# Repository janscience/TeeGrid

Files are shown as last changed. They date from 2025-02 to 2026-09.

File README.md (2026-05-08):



# TeeGrid

Record electric fish with electrode arrays based on
[Teensy](https://www.pjrc.com/teensy/) microcontrollers.

Based on the [TeeRec](https://github.com/janscience/TeeRec) library,
inspired by Stefan Mucha's
[EOD-Logger](https://github.com/muchaste/EOD-Logger), the
[MicroConfig](https://github.com/janscience/MicroConfig) library, the
[ESensors](https://github.com/janscience/ESensors) library, and the
[Teensy_Amp](https://github.com/janscience/Teensy_Amp) amplifiers.

teensyamp

## R4 logger with sensors

Logger for 2 to 16 channels based on
[Teensy_Amp R4.1](https://github.com/janscience/Teensy_Amp/tree/main/R4.1) or
[Teensy_Amp R4.2](https://github.com/janscience/Teensy_Amp/tree/main/R4.2) with additional environmental sensors. [Read more](examples/R4-sensors-logger/).

submerged logger

## R4 logger

Logger for 2 to 16 channels based on
[Teensy_Amp R4.1](https://github.com/janscience/Teensy_Amp/tree/main/R4.1) or
[Teensy_Amp R4.2](https://github.com/janscience/Teensy_Amp/tree/main/R4.2). [Read
more](examples/R4-logger/).

## R40 logger

Logger for 2 to 8 channels based on [Teensy_Amp
  R4.0](https://github.com/janscience/Teensy_Amp/tree/main/R4.0). [Read
  more](examples/R40-logger/).

## 8-channel logger

Logger for 8 channels based on [Teensy_Amp
  R1.0](https://github.com/muchaste/Teensy_Amp/tree/main/R1.0).  [Read
  more](examples/8channel-logger/).

8channel

## 8-channel logger with sensors

A variant of the [8-channel logger](8channel-logger/) that
supports a variety of environmental sensors. [Read
more](examples/8channel-sensors-logger/).

## Configuration and testing GUI

The [`loggerconf`](utils/loggerconf.py) GUI allows you to configure
the loggers, set the real-time clock, and provides many diagnostic features.

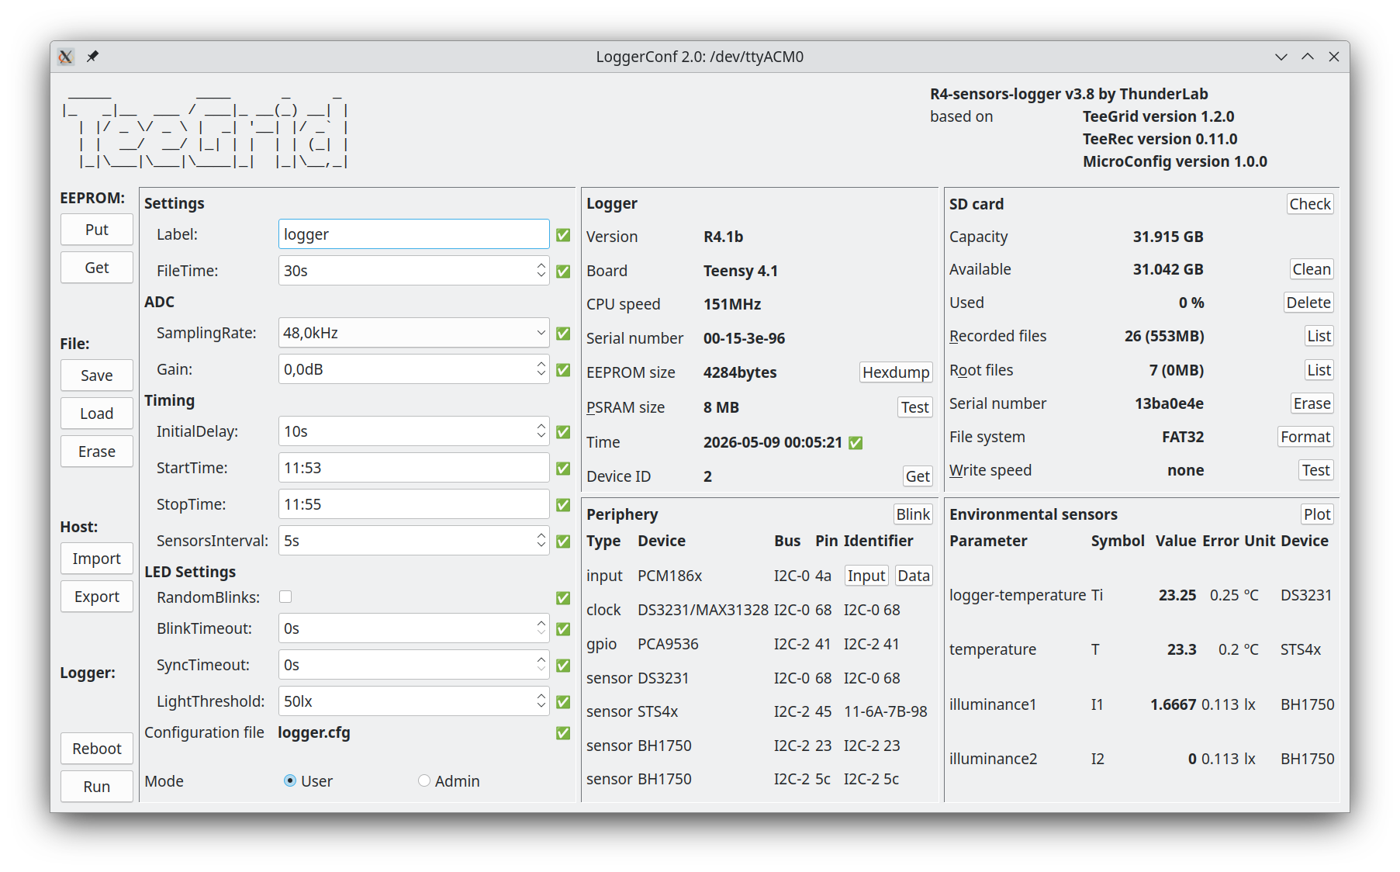
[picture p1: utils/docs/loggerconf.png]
loggerconf


You need to install `pymicroconfig` first, as described
[here](https://github.com/janscience/MicroConfig/tree/main/pymicroconfig).

And you need to install [`pyqtgraph`](https://www.pyqtgraph.org/):
```
pip install pyqtgraph
```

Then navigate to `Arduion/libraries/TeeGrid/utils` and run
```
python loggerconf.py
```

## Housings

- [PVC-tube housings](doc/pvc-tube-housing)

housing

## Electrodes

- [Stainless-steel electrodes](doc/steel-electrodes)

electrodes

## Installation

- [Installation instructions](doc/installation) for the TeeGrid
  library and sketches.

## Resources

Ideas to solve the syncrhonization problem of multiple loggers:

- [Low-cost synchronization of high-speed audio and video recordings
  in bio-acoustic experiments](https://doi.org/10.1242/jeb.173724)
- [Bio-acoustic tracking and localization using heterogeneous,
  scalable microphone
  arrays](https://doi.org/10.1038/s42003-021-02746-2)

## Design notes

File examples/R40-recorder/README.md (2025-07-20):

# R4.0 recorder

Recorder for 2, 4, 6, or 8 channels based on [TeensyAmp
  R4.0](https://github.com/janscience/Teensy_Amp/tree/main/R4.0)
  connected to a [Teensy 4.1](https://www.pjrc.com/store/teensy41.html).

Designed by Jan Benda in July 2025.

## Dependencies

The [`R40-recorder.ino`](R40-recorder.ino) sketch is based on the
[TeeRec](https://github.com/janscience/TeeRec) library.

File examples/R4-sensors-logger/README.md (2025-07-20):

# R4.x sensors logger

Logger for 2 to 16 channels based on

- [Teensy_Amp R4.1](https://github.com/janscience/Teensy_Amp/tree/main/R4.1) and/or
- [R4.2](https://github.com/janscience/Teensy_Amp/tree/main/R4.2)
  connected to a
- [Teensy 4.1](https://www.pjrc.com/store/teensy41.html)

with additional sensors (see [Sensors-V1](../../doc/sensors/sensors-v1)).

Software based on the

- [TeeRec](https://github.com/janscience/TeeRec) and the
- [ESensors](https://github.com/janscience/ESensors) libraries.

Designed by Jan Benda and Patrick Weygoldt in September 2023.

submerged logger

## Assembly

Connect the wires from the [electrodes](../../doc/steel-electrodes) to the screw terminals of the amplifier...

channels

... using this [color code](https://github.com/janscience/TeeGrid/tree/main/doc/steel-electrodes#international-color-code)

Connect the coin battery and the temperature sensor:

periphery

connections

- Status LED: plug onto the two pins on the
  [R4.1](https://github.com/janscience/Teensy_Amp/tree/main/R4.1) PCB
  top left corner. When running the
  [`R4-sensors-logger.ino`](R4-sensors-logger.ino) sketch, and this
  LED does not light up, then unplug, turn by 180 degrees, and plug in
  again.

- Coin battery: make sure the +3.3V (hopefully red) is on the side,
  and ground (hopefully black) is in the center of the Teensy. Better
  is to check the polarity of the coin battery using a multimeter.

- Temperature sensor: the data wire goes on third pin (counted from
  the SD card end of the Teensy, pin 35). Power is the red cable,
  ground is the red cable with the black line on the outside.

## Installation

See the [installation instructions](../../doc/install.md) for the
TeeGrid library.

## Software setup

The behavior of the logger sketch can be modfied in various
ways. Either by editing some variables directly in the sketch, as
described here, or by a configuration file provided on the SD card, as
described in the next section.

*WARNING* the settings of the config file overwrite the settings made
 in the sketch!

For editing the sketch, open the
[`R4-sensors-logger.ino`](R4-sensors-logger.ino) sketch in the Arduino
IDE (`File` - `Open`, `Ctrl-O`, or `File` - `Examples` - `TeeGrid` -
`R4-senosrs-logger`) and edit it appropriately.  In the top section
marked as `Default settings` you may adapt some settings according to
your needs as described in the next sections.

Once you modified the sketch to your needs, compile and upload it to
the Teensy (`Ctrl-U`). Open the serial monitor (`Ctrl-Shift-M`) and
check the output of the sketch.

### Data acquisition

The first section is about the data acquisition:

- `NCHANNELS`: the number of channels you want to record. If you use a
  single [Teensy_Amp R4.1](https://github.com/janscience/Teensy_Amp/tree/main/R4.1)
  or [R4.2](https://github.com/janscience/Teensy_Amp/tree/main/R4.2) then set this to 8.
  If you use [both of them stacked
  together](https://github.com/janscience/Teensy_Amp/tree/main/R4.1-R4.2),
  then set it to 16.
- `SAMPLING_RATE`: the sampling rate you want to use (48000 or 96000 Hertz).
- `PREGAIN`: the gain of the preamplifier, either 10 (default) or 1
  (for recording electric eels). *Make sure this is is set to the right number!*
- `GAIN`: additional gain of the ADC in dB. 0: x1, 20: x10, 40: x100.

For wavefish use an amplifier with a pregain of 10 and set the gain
to 20dB. For electric eels, use an amplifier with a pregain of 1 and
set the gain to 0dB.

### File naming and size

The second section is about the files that store the data on the SD
card.

- `PATH`: name of the directory, in which the files are stored.
- `FILENAME`: name of the files that store the recorded data. See
  below for special strings to insert data and time.
- `FILE_SAVE_TIME`: each file will store that many seconds of the
  continuous recording.
- `INITIAL_DELAY`: after startup, wait for the specified time in
  seconds before writing data to files.

#### Special strings for the file name

The following special strings in the file name are replaced by
the current date, time, or a number:

- `DATE`: the current date as ISO string (YYYY-MM-DD)
- `SDATE`: "short date" - the current date as YYYYMMDD
- `TIME`: the current time as ISO string but with dashes instead of colons (HH-MM-SS)
- `STIME`: "short time" - the current time as HHMMSS
- `DATETIME`: the current date and time as YYYY-MM-DDTHH-MM-SS
- `SDATETIME`: "short data and time" - the current date and time as YYYYMMDDTHHMMSS
- `ANUM`: a two character string numbering the files: 'aa', 'ab', 'ac', ..., 'ba', 'bb', ...
- `NUM`: a two character string numbering the files: '01', '02', '03', ..., '10', '11', ...
- `NUM3`: a three character string numbering the files: '001', '002', '003', ..., '010', '011', ..., '100', '101', ...
- `NUM4`: a four character string numbering the files: '0001', '0002', '0003', ..., '0010', '0011', ..., '0100', '0101', ..., '1000', '1001', ...

### Pins and Sensors

- `LED_PIN`: the [Teensy pin](https://github.com/janscience/Teensy_Amp/blob/main/R4.1/images/teensy41-R41-pinout.png) to which the LED on the amplifier is connected to.
- `TEMP_PIN`: the [Teensy pin](https://github.com/janscience/Teensy_Amp/blob/main/R4.1/images/teensy41-R41-pinout.png) to which the DATA wire of the [Dallas
  DS18x20](https://github.com/janscience/ESensors/blob/main/docs/chips/ds18x20.md)
  temperature sensor is connected to.
- `SENSORS_INTERVAL`: interval between sensor readings in seconds

## Configuration file

Most of the settings described above can be configured via a
configuration file. Simply place a configuration file named
[`logger.cfg`](logger.cfg) into the root folder of the SD card. If
present, this file is read once on startup. The configuration file
will overwrite the settings made in the
[`R4-sensors-logger.ino`](R4-sensors-logger.ino) sketch.

The content of the configuration file should look like this:

```txt
Settings:
  Path:            recordings
  FileName:        logger1-SDATETIME.wav
  FileTime:        5min
  InitialDelay:    10s
  SensorsInterval: 10.0s
ADC:
  SamplingRate: 48.0kHz
  NChannels:    16
  Gain:         20.0dB
``` 

Everything behind '#' is a comment. All lines without a colon are
ignored.  Unknown keys are ignored but reported. Times and frequencies
understand various units (s, min, h, kHz, MHz). Check the serial
monitor of the Arduino IDE (`Ctrl+Shif+M`) to confirm the settings.

## Real-time clock

For proper naming of files, the real-time clock needs to be set to the
right time. The easiest way to achieve this, is to compile and upload
the [`R4-sensors-logger.ino`](R4-sensors-logger.ino) sketch from the
Arduino IDE. The upload also sets the on-bard real-time clock to the
time of the computer. Use the serial monitor to check the output of
the sketch. At the beginning it reports the time. Disconnect the
Teensy from the USB and simply reconnect it. If it then reports on the
serial monitor the right time, the real time clock is properly set and
is properly powered by the coin battery.

Alternatively, you may copy a file named `settime.cfg` into the root
folder of the SD card. This file contains a single line with a date
and a time in the following format:
``` txt
YYYY-MM-DDTHH:MM:SS
```

In a shell you might generate this file via
```sh
date +%FT%T > settime.cfg
```
and then edit this file to some time in the near future.

Insert the SD card into the Teensy. Start the Teensy exactly at the
time that is written into the `settime.cfg` file by connecting it to
power. On start up the
[`R4-sensors-logger.ino`](R4-sensors-logger.ino) sketch reads in the
`settime.cfg` file, sets the real-time clock to this time, and then
deletes the file from the SD card to avoid resetting the time at the
next start up.

## Check logger function

Run the logger from the Arduino IDE and check the output on the serial
monitor (`Ctrl+Shif+M`). You should then see something like the
following. The comments after `#` have been inserted afterwards to
explain what is important:

```txt
=======================================================================

RTC (on-board) current time: 2024-08-12T10:43:13      # this should be the current time and not 2019-01-01T00:00:00

Configuration file "logger.cfg" not found or empty.   # if you use a configuration file, it should be reported here

Settings:                                             # check whether these configuration settings are right
  Path:            recordings
  FileName:        logger1-SDATETIME.wav
  FileTime:        300s
  PulseFreq:       0Hz
  InitialDelay:    10s
  SensorsInterval: 10.0s
ADC:
  SamplingRate: 48.0kHz
  NChannels:    16
  Gain:         0.0dB

1 of 1 environmental sensor available, read every 10s:  # check whether all sensors are detected
  water-temperature T_water (ºC):	 on DS18B20 device (ID: 28 43 AA 67 B2 23 06 10) at a resolution of 0.06ºC.

Setup PCM186x 0 on TDM 0: configured for 4 channels  # make sure all 4 chips are detected and configured for 4 channels
Setup PCM186x 1 on TDM 0: configured for 4 channels
Setup PCM186x 2 on TDM 1: configured for 4 channels
Setup PCM186x 3 on TDM 1: configured for 4 channels

TDM settings:                                        # check sampling rate and channels
  rate:       48.0kHz
  resolution: 32bits
  channels:   16
  swap l/r:   1
  buffer:     2.73s (2097152 samples)
  DMA time:   1.3ms

Save recorded data in folder "recordings".

logger1-20240812T104327.wav                         # this is the first file in which recorded data are stored
2024-08-12T10:43:27: T_water = 27.12ºC              # this is the measured temperature
2024-08-12T10:43:35: T_water = 27.12ºC
2024-08-12T10:43:45: T_water = 27.12ºC
...
```

## Logging

1. *Format the SD card.* (see section below)
2. Optional: Copy your logger.cfg file onto the SD card.
3. Insert the SD card into the Teensy.
4. Connect the Teensy to a battery/power bank.
5. Close the housing.
6. Place the logger whereever you want to record electric fishes.
7. Let the logger record the data.
8. Check the status LED whether it blinks every 5 secods. If it is not
   blinking, then something is wrong.
9. After many hours (or days, depending on the capacity of your powerbanks),
   collect the logger.
10. Open it, and disconnect the Teensy from the powerbank.
11. Optionally repeat 4. - 10. with a freshly charged powerbank
    until the SD card is full.
12. Take out the SD card and store the data on a harddrive.
    Don't forget to backup the data.

### Formatting the SD card

The SD card needs to be reformatted once in a while. The logger runs
until the battery is drained and therefore cannot properly close the
last files. This leaves the file system in a corrupted state, which
apparently results in very long delays when writing to the SD card
again.

You may use the sketch provided by the SdFat library for formatting
the SD card directly on a Teensy: In the Arduino IDE menu select
`File` - `Examples`, browse to the last section ("Examples from custom
libraries"), select `SdFat` and then `SdFormatter`. Upload the script
on Teensy and open the serial monitor. Follow the instructions on the
serial monitor.

Or use the `SdFormatter` script provided in TeeGrid. This is the same
script as the one described above, but without user interaction. When
running it will erase and format the SD card inserted into the Teensy.
You find this script under `File` - `Examples` - `TeeGrid` -
`SdFormatter`.

Formatting from a computer also helps, but this omits the erasing
part.

### Status LED

The on-board LED of the Teensy and the LED of the [Teensy_Amp
R4.1](https://github.com/janscience/Teensy_Amp/tree/main/R4.1) or
[R4.2](https://github.com/janscience/Teensy_Amp/tree/main/R4.2)
indicate the following events:

- On startup the LED is switched on during the initialization of the
  data acqusition and SD card. This can last for up to 2 seconds
  (timeout for establishing a serial connection with a computer).

- For the time of the initial delay (nothing is recorded to SD card)
  a double-blink every 2s is emitted.

- Normal operation, i.e. data acquisition is running and data are
  written to SD card: the LED briefly flashes every 5 seconds (file
  time larger than 30s) or every 2 seconds (file time smaller than
  30s).

- Whenever a file is closed and the next one opened, the LED lights for
  1 second. Then it continues with flashes every 5 seconds.

- The LED is switched off if no data can be written on the SD card (no
  SD card present or SD card full) or data acquisition is not working.
  In this case, connect the Teensy to a computer and open the serial
  monitor of the Arduino IDE (`Ctrl+Shif+M`). On startup the settings
  for the data acquisition are reported and in case of problems an
  error message is displayed.

## Files

Analog input data are stored on the SD card as wave files in the
directory specified by `PATH` with names `FILENAME`. The metadata
in these files indicate the time when the file was created and the
overall gain of the hardware.

You may use the Python
[audioio](https://github.com/janscience/audioio) package to read the
recorded channels and the metadata. Or use the
[DataLoader](https://github.com/bendalab/thunderlab/blob/main/src/thunderlab/dataloader.py)
from the [thunderlab](https://github.com/bendalab/thunderlab)
package. The latter applies the gain setings directly to the data.

For viewing the data, you may use any audio tool. Or check out
[audian](https://github.com/bendalab/audian).

The sensor data are stored as a csv file with the very same name as
the first data file, but with `-sensors.csv` added to it.

## Improvements

- Add sensor for illumination and water conductivity. Make a PCB for this!

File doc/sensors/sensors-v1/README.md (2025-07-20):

# Sensors V1

Temperature and illumination sensors and status LEDs for
[R4-sensors-logger](../../../examples/R4-sensors-logger).

## Sensors

### Rohm BH1750 ambient light sensor

- [data sheet](https://github.com/janscience/ESensors/blob/main/docs/chips/datasheets/bh1750.pdf)
- [ESensors library](https://github.com/janscience/ESensors/blob/main/docs/chips/bh1750.md)

### TI TMP119 temperature sensor

- [data sheet](https://github.com/janscience/ESensors/blob/main/docs/chips/datasheets/tmp119.pdf)

## Circuit

- [EAGLE schematics file](Sensors-V1.sch)
- [EAGLE circuit board](Sensors-V1.brd)

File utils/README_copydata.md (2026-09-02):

# `copydata.py`

Copies logger SD cards onto the field drive: compress, sort, verify. An
alternative to `copydata.sh` for card sets big enough that you want the copy to
prove itself. Standard library only — no `pip install` on a field laptop. Needs
`wavpack`/`wvunpack`; `zstd` as fallback, `--codec none` needs nothing.

New to it: start with the [tutorial](TUTORIAL_copydata.md).

## Use

```
python3 utils/copydata.py list                                    # what is on the cards
python3 utils/copydata.py copy /media/me/HDD/iriri26
python3 utils/copydata.py verify /media/me/HDD/iriri26 --only-unverified --jobs 4
python3 utils/copydata.py restore DEST ./unpacked                 # back to plain .wav
```

`copy` is resumable: re-running skips every file the manifest records as fully
written, so an interruption costs you only the file it died on.

## Verification

Every file is sha256'd while it streams off the card. That hash is free — it is
the same read — and it goes into `copy_manifest.jsonl` on the drive. Reading
files *back* is what costs time:

| `--verify` | reads back | 4 x 500 GB |
|---|---|---|
| `sample` (default) | 5% of each deployment, every sidecar | ~6.3 h |
| `full` | everything | ~12 h |
| `none` | nothing | ~6 h |

`sample` does not give up proof, it defers it. `verify` checks the drive against
the stored hashes and does not need the cards, so run it once they are out of
the reader — but before reformatting anything.

`--sample-percent P` (default 5) is a share and not a count because folders
differ by three orders of magnitude: a 20 min test is 4 files, a 3 day recording
at 5 min per file is ~864. At the default that 3 day folder gets 44 probes, one
per ~1.7 h of recording.

## Codec

`wavpack -f` is the default. Measured on three flona2025 WAVs (16 ch, 48 kHz,
16-bit, 461 MB) spanning a busy night grid, a grid with 8 dead channels, and a
quiet line recording:

| codec | saved | compress MB/s/core | decompress |
|---|---|---|---|
| `zstd -3` | 84.7 % | ~258 | ~700 |
| `gzip -6` | 86.6 % | ~27 | ~660 |
| **`wavpack -f`** | **88.6 %** | **~93** | ~88 |
| `wavpack -h -x4` | 89.2 % | ~3.5 | ~90 |
| `xz -6` | 91.5 % | ~0.9 | ~143 |

`gzip` is beaten on both axes. These are not general-purpose bytes — the
recordings use only 3-11 of their 16 bits, so per-channel prediction plus Rice
coding fits them better than an LZ matcher. `wavpack -f` also beats wavpack's
own default level here. FLAC is not an option at all: the format caps at 8
channels. `xz` is the smallest but runs at ~1 MB/s/core, slower than the cards
themselves — use it at the lab (`restore`, then `copy --codec xz`).

In the field the cards are the bottleneck, so the compression is free.

## What ends up on the drive

Sessions are named `<site>-<grid>-<dev>-<timestamp>` and are filed to match:

```
DEST/
├── copy_manifest.jsonl        # per file: source, sha256, codec, WAV metadata
├── copy_logs/
├── site01/grid01/site01-grid01-dev01-20260826T175746/
│   ├── site01-grid01-dev01-20260826T175746.wv
│   └── site01-grid01-dev01-20260826T175746-sensors.csv   # sidecars stay plain
├── site02/grid01/site02-grid01-dev01-20260827T090000__mac1b9999/   # only on a real collision
└── logger24A-20260826T1757/   # name does not parse: left at the top level
```

A folder whose name does not match the convention is left at the top level
rather than filed under a guessed site, so old and new cards can be copied in
one run. `--flat` turns the nesting off.

The manifest is part of the archive. Without it you have files but no proof they
match the cards, and `verify` and `restore` have nothing to check against.

## Worth knowing

* **Never writes to a card, never deletes anything.** Ejecting and reformatting
  stay manual, on purpose.
* **Copied files are read-only (`0444`).** Files only, not directories, so
  resume and `verify` still work. `--no-protect` disables it. Does nothing on
  exFAT/NTFS — the summary says so rather than pretending.
* **The custom `LIST`/`INFO` chunk survives.** `wvunpack` reconstructs a
  byte-identical `.wav`, `DTIM` included. It can also be read without decoding:
  wavpack keeps the original RIFF header in the first 8 KB of the `.wv`.
* **0-byte WAVs are skipped** (`--keep-empty` to copy them). A scan of 23,699
  flona2025 WAVs found 61, always the last file of a deployment.
* **`verify --jobs N`** checks N files at a time (default `min(4, cores)`) and
  writes each outcome back, so a file that fails loses any earlier "verified"
  claim.
* **`--codec-threads`** defaults to `cores / cards`, which keeps each card
  streaming sequentially — the right pattern for SD cards and a spinning drive.

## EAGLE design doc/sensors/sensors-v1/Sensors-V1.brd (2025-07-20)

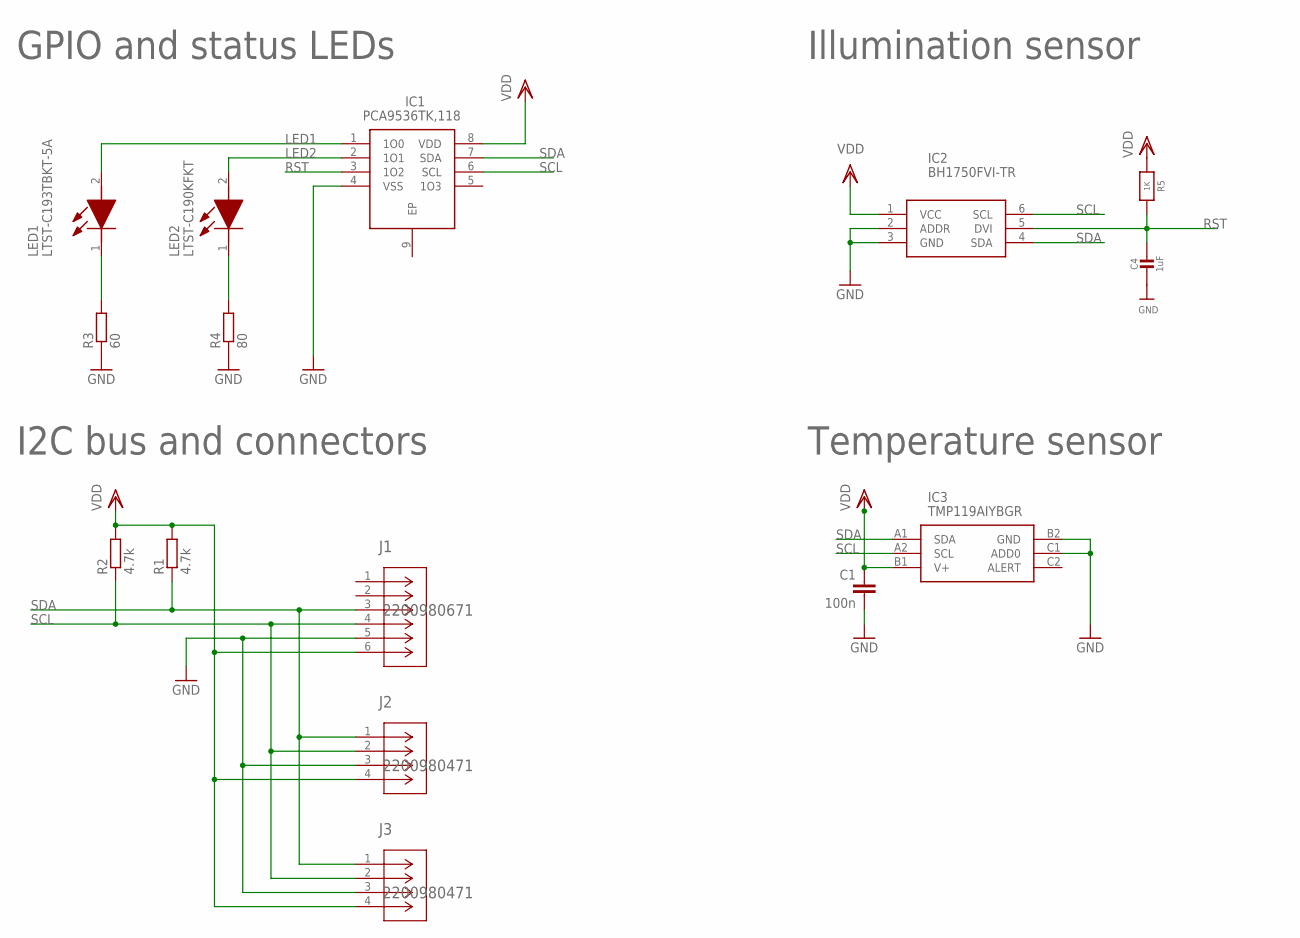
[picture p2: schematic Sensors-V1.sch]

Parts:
C1: 100n; C0603
C4: 1uF; 0603-NO
IC1: PCA9536TK,118; SON50P300X300X100-9N
IC2: BH1750FVI-TR; WSOF6
IC3: TMP119AIYBGR; BGA6C40P2X3_95X149X52
J1: 2200980671; CONN_2200980000-SD_06_MOL
J2, J3: 2200980471; CONN_2200980000-SD_04_MOL
LED1: LTST-C193TBKT-5A; LEDC1608X45N
LED2: LTST-C190KFKT; LEDC1607X80N
R1, R2: 4.7k; R0603
R3: 60; R0603
R4: 80; R0603
R5: 1K; 0603-NO

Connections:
GND: C1.2, C4.2, IC1.4 (VSS), IC2.2 (ADDR), IC2.3 (GND), IC3.B2 (GND), IC3.C1 (ADD0), J1.5, J2.3, J3.3, R3.1, R4.1
LED1: IC1.1 (1O0), LED1.2 (A)
LED2: IC1.2 (1O1), LED2.2 (A)
unnamed: LED1.1 (K), R3.2
unnamed: LED2.1 (K), R4.2
RST: C4.1, IC1.3 (1O2), IC2.5 (DVI), R5.2
SCL: IC1.6 (SCL), IC2.6 (SCL), IC3.A2 (SCL), J1.4, J2.2, J3.2, R2.1
SDA: IC1.7 (SDA), IC2.4 (SDA), IC3.A1 (SDA), J1.3, J2.1, J3.1, R1.1
VDD: C1.1, IC1.8 (VDD), IC2.1 (VCC), IC3.B1 (V+), J1.6, J2.4, J3.4, R1.2, R2.2, R5.1

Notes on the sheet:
Temperature sensor
Illumination sensor
GPIO and status LEDs
I2C bus and connectors

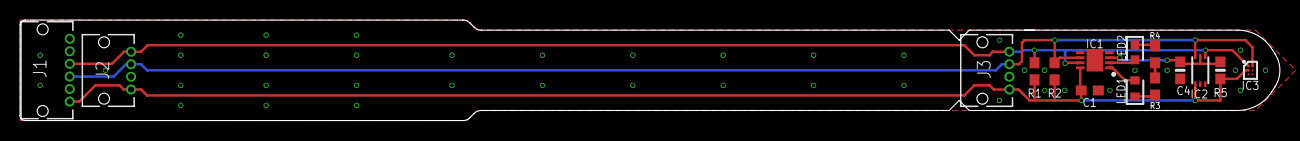
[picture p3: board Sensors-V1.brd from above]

Board: 2 copper layers, 125.4 x 10.0 mm, 15 parts (0 on the bottom side), 9 nets.

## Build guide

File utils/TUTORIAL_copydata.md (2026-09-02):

# Getting a stack of SD cards onto the field drive

Walkthrough of `copydata.py`. Reference material — codec table, archive layout,
all options — is in [`README_copydata.md`](README_copydata.md).

Three things in one pass: **copy** each card into its own deployment folder
filed by site and grid, **shrink** every WAV to about an eighth without losing a
sample, and **check** the copy so you can reformat the card without crossing
your fingers.

Plug in the cards and the destination drive. Nothing else to prepare — the tool
finds the cards itself and never writes to one. You need `python3` and
`wavpack`; if something is missing it says so.

## 1. Look

```
python3 utils/copydata.py list
```

Reads the WAV headers, shows what it found and where each thing would go.
Writes nothing. Worth doing once to spot a card that did not mount, or a logger
that recorded far less than expected.

## 2. Copy

```
python3 utils/copydata.py copy /media/you/FIELD_HDD/iriri26
```

Prints a plan, asks once, then works. Cards are read in parallel, one file at a
time each.

```
  TOTAL: 7 files, 23.4 MB
  skipping 1 empty (0-byte) wav(s) -- the file the logger had open
  codec: wavpack -f
  verify: spot check 5 of 7 files (71.4%)
  estimated on destination: ~3.0 MB  (free: 28.8 GB)
```

Then walk away. Expect roughly card speed; compression is not the bottleneck.

## 3. Read the last lines

```
copied   : 7 files, 23.4 MB read -> 3.0 MB written
ratio    : 0.126 (87.4% saved)

Spot check passed: 5 of 7 files were read back and re-hashed.
Every file's source hash is in the manifest, so any of them can still be
proven -- but the rest are NOT yet confirmed on the destination.
```

Read that literally, both ways. For the checked files the drive holds exactly
what the card held. The rest are written and hashed, but not yet read back —
that is step 4.

If you see `FAILED (n)`: **do not reformat the cards.** Run the same command
again; finished files are skipped and only the broken ones retried.

## 4. Prove the rest

The spot check is sized to catch a card or drive going bad — 5% of each
deployment, evenly spread. It is not proof of every file. That is one more
command:

```
python3 utils/copydata.py verify /media/you/FIELD_HDD/iriri26 \
    --only-unverified --jobs 4
```

It reads the destination, not the cards, so **unplug them first** and run it
over supper. Expect roughly half the time the copy took. You want
`bad: 0   missing: 0`. Anything else and the cards are still the only good copy.

## 5. Only now, reformat

Ejecting and reformatting are left to you. The tool never deletes anything.

## Getting `.wav` files back

```
python3 utils/copydata.py restore DEST ./unpacked --only site01/grid01
```

`--only` matters: one deployment is ~270 GB unpacked. Each restored file is
checked against its stored checksum on the way out.

Often you do not need this. `wvunpack` seeks, so a reader can pull a window
straight out of a `.wv`: a 10 s window costs 0.19 s whether it starts at 0 s or
4 min in, and a full 300 s file decodes in 5.9 s (~50x realtime).

```
wvunpack -q -y --skip=00:02:00 --until=+00:00:10 -o - FILE.wv
```

Note the header of a *partial* decode is synthetic and carries no `LIST`/`INFO`
metadata. That metadata is not lost — wavpack keeps the original RIFF header in
the first 8 KB of the `.wv`, and `copy_manifest.jsonl` has the same fields
already parsed.

## The commands

| | |
|---|---|
| `list` | what is on the cards, where it would go |
| `copy DEST` | copy, compress, spot-check |
| `verify DEST` | prove the drive against the manifest, cards not needed |
| `restore DEST OUT` | back to plain `.wav` |

## Worth knowing

* The drive is filed by site and grid: `DEST/site01/grid01/<session>/`.
* Copied files are read-only. Resume and `verify` still work; `--no-protect`
  turns it off.
* Re-running `copy` is safe and resumes.
* In a hurry: `--verify none` skips the spot check, `--verify full` reads
  everything back and roughly doubles the run.

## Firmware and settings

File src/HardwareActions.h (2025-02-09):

/*
  HardwareActions - Actions for diagnosing external hardware.
  Created by Jan Benda, January 5th, 2025.
*/

#ifndef HardwareActions_h
#define HardwareActions_h


#include <Action.h>
#include <Menu.h>
#include <ESensors.h>


class ESensorsAction : public Action {

 public:

  /* Initialize and add to default menu. */
  ESensorsAction(const char *name, ESensors &sensors);

  /* Initialize and add to configuration menu. */
  ESensorsAction(Menu &menu, const char *name, ESensors &sensors);

protected:

  ESensors &Sensors;
};


class ESensorSensorsAction : public ESensorsAction {

 public:

  using ESensorsAction::ESensorsAction;

  /* Print infos about available environmental sensors. */
  virtual void execute(Stream &stream=Serial, unsigned long timeout=0,
		       bool echo=true, bool detailed=false);
};


class ESensorDevicesAction : public ESensorsAction {

 public:

  using ESensorsAction::ESensorsAction;

  /* Print infos about available environmental sensor devices. */
  virtual void execute(Stream &stream=Serial, unsigned long timeout=0,
		       bool echo=true, bool detailed=false);
};


class ESensorRequestAction : public ESensorsAction {

 public:

  using ESensorsAction::ESensorsAction;

  /* Request sensor values. */
  virtual void execute(Stream &stream=Serial, unsigned long timeout=0,
		       bool echo=true, bool detailed=false);
};


class ESensorValuesAction : public ESensorsAction {

 public:

  using ESensorsAction::ESensorsAction;

  /* Print sensor values. If detailed, just get previously requested values.
     Otherwise request and read them. */
  virtual void execute(Stream &stream=Serial, unsigned long timeout=0,
		       bool echo=true, bool detailed=false);
};


#endif

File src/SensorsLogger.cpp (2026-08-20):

#include <PowerSave.h>
#include <LoggerSettings.h>
#include <SensorsLogger.h>


SensorsLogger::SensorsLogger(Input &aiinput,
			     ESensors &sensors,
			     SDCard &sdcard,
			     RTClock &rtclock,
			     Blink &blink) :
  Logger(aiinput, sdcard, rtclock, blink),
  Sensors(sensors),
  NLightSensors(0),
  IlluminationThreshold(0.0) {
}


SensorsLogger::SensorsLogger(Input &aiinput,
			     ESensors &sensors,
			     SDCard &sdcard,
			     RTClock &rtclock,
			     Blink &blink,
			     Blink &errorblink,
			     Blink &syncblink) :
  Logger(aiinput, sdcard, rtclock, blink, errorblink, syncblink),
  Sensors(sensors),
  NLightSensors(0),
  IlluminationThreshold(0.0) {
}


void SensorsLogger::setupSensors() {
  Sensors.setPrintTime(ESensors::NO_TIME);
  Sensors.start();
  for (uint8_t k=0; k<Sensors.sensors(); k++) {
    if (Sensors[k].available() && (strcmp(Sensors[k].unit(), "lx") == 0) &&
	(NLightSensors < MaxLight))
      LightSensors[NLightSensors++] = &Sensors[k];
  }
}


void SensorsLogger::checkVoltage(float minvoltage) {
  ESensor *vbat = Sensors.sensor("battery-voltage");
  if (vbat != 0 && minvoltage > 0.0) {
    float volt = vbat->read();
    if (volt < minvoltage) {
      stop();
      StatusLED.switchOff();
      ErrorLED.switchOff();
      SyncLED.switchOff();
      Serial.printf("HALT --- battery voltage %.2fV lower than %.2fV!\n",
		    volt, minvoltage);
      Serial.println();
      Serial.println();
      Serial.flush();
      shutdown_teensy();
    }
  }
}


void SensorsLogger::startSensors(float interval,
				 float lightthreshold) {
  IlluminationThreshold = lightthreshold;
  Sensors.setInterval(interval);
  Sensors.setPrintTime(ESensors::ISO_TIME);
  Sensors.reportDevices();
  Sensors.report();
  Sensors.start();
  Sensors.read();
  Sensors.start();
  Sensors.read();
}


void SensorsLogger::start(float filetime) {
  Logger::start(filetime);
  openSensorsFile();
}


void SensorsLogger::start(float filetime, Config &config) {
  Logger::start(filetime, config);
  openSensorsFile();
}


void SensorsLogger::start(float filetime, Config &config,
			  Menu &amplifier) {
  Logger::start(filetime, config, amplifier);
  openSensorsFile();
}


void SensorsLogger::openSensorsFile() {
  String sname = File.name();
  sname.replace(".wav", "-sensors");
  Sensors.openCSV(*Disk, sname.c_str());
  Serial.print("Write sensor data to ");
  Serial.println(sname);
}


bool SensorsLogger::storeSensors() {
  if (Sensors.update(StatusLED.isOn() || SyncLED.isOn())) {
    if (Sensors.pendingCSV())
      Sensors.writeCSV();
    Sensors.print(true, true);
    // strongest illumination:
    if (NLightSensors > 0) {
      float illumination = 0.0;
      for (size_t k=0; k<NLightSensors; k++) {
	if (LightSensors[k]->value() > illumination)
	  illumination = LightSensors[k]->value();
      }
      if (illumination < IlluminationThreshold) {
	StatusLED.disablePins();
	SyncLED.disablePins();
      }
      else {
	StatusLED.enablePins();
	SyncLED.enablePins();
      }
    }
    return true;
  }
  return false;
}


void SensorsLogger::closeSensorsFile() {
  Sensors.closeCSV();
}


bool SensorsLogger::update(float stopvoltage) {
  Logger::update(stopvoltage);
  return storeSensors();
}


void SensorsLogger::synchronize(float stopvoltage) {
  checkVoltage(stopvoltage);
}


void SensorsLogger::stop() {
  closeSensorsFile();
  Logger::stop();
}

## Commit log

2024-10-24 fixed PulseFreq and possible sampling rates
    [LoggerFileStorage.cpp, R4-logger.ino, R4-sensors-logger.ino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]
2024-11-24 [loggerconf] added device to logger info
2024-11-26 [loggerconf] added list root file button
2024-11-28 [loggerconf] switch into detailed mode
2024-11-29 [loggerconf] switch off echoing input
2024-11-30 [loggerconf] try to reboot already connected Teensy
    [LoggerFileStorage.cpp, R4-logger.ino]
2024-12-02 [LoggerFileStorage] set current CPU speed to WaveHeader
2024-12-04 [loggerconf] transmit detcts wrong value and still returns to main menu
    [R4-logger.ino]
2024-12-07 [loggerconf] added SD card formatting buttons
2024-12-13 [loggerconf] added run button
2024-12-14 [loggerconf] fixed mising unit bug
    [R4-logger.ino]
2024-12-14 [loggerconf] removed some prints
2024-12-16 [loggerconf] delete button next to used
2025-01-04 [SensorsLoggerFileStorage] support sensors
2025-01-05 [HardwareActions] report sensor infos
2025-01-05 [loggerconf] added sensors info
2025-01-06 [loggerconf] added input devices
2025-01-10 [R4-logger] added input devices to menu
2025-01-10 [R4-logger] added rtclock devices to diagnostics
2025-01-10 [loggerconf] update for sensor devices
2025-01-11 [HardwareActions] sensor readings
2025-01-11 [HardwareActions] fixed sensor readings
    [R4-sensors-logger.ino, SensorsLogger.cpp]
2025-01-11 [HardwareActions] sensor request
2025-01-11 [HardwareActions] read or get sensor
2025-01-11 [loggerconf] display sensor values
2025-01-13 [loggerconf] adapted SensorsInfo to removed colon
2025-01-18 [loggerconf] plot sensor readings with QChart
2025-01-23 [loggerconf] plot sensor readings with pyqtgraph
2025-01-24 [loggerconf] improved sensors plot
2025-01-29 [loggerconf] fixed button/label overlap
2025-01-30 [loggerconf] added power spectra
2025-02-17 [SetupPCM] added missing configure()
    [SetupPCM.cpp]
2025-04-02 [loggerconf] updated sensors handling
2025-04-05 [8channel-logger] fixed diagnostic mneu
    [8channel-sensors-logger.ino]
2025-06-23 [loggerconf] added reboot button
2025-07-20 [sensors] added schematics and board
    [Sensors-V1.brd, Sensors-V1.sch]
2025-08-05 [R4-logger] simplified power down of CAN
2025-08-06 [R4-logger] added device id support
2025-08-09 [loggerconf] support DeviceID readout
2025-08-11 [R4-sensors-logger] need to initialize sensors before file check
2025-08-11 [R4-sensors-logger] default device ID is -1
2025-08-11 [R4-sensors-logger] added temperature sensor of real time clock
2025-08-11 [R4-sensors-logger] detect R41b amplifier
2025-08-11 [Logger] print actual working directory
2025-08-23 [R4-sensors-logger] added gpio and ligh sensors
2025-08-23 [R4-sensors-logger] added STS40 temperature sensor
2025-08-23 [R4-sensors-logger] light sensor is working
2025-08-23 [R4-sensors-logger] added IR LED
2025-08-23 [R4-sensors-logger] renamed to DigitalIOPCA9536
2025-08-23 [R4-sensors-logger] support of three LEDs
2025-08-23 [R4-sensors-logger] switch LEDs on only if no sensor reading
2025-08-23 [R4-sensors-logger] retreive sensor reading only if no LED is on
2025-08-24 [R4-sensors-logger] take blink timeout from settings
2025-08-25 [R4-sensors-logger] added gpio to devices
2025-08-26 [R4-sensors-logger] changed LED usage
2025-08-26 [R4-logger] removed SPI.h
2025-08-31 [R4-sensors-logger] rtc temp first
2025-08-31 [Logger] second status LED has index 1
2025-09-05 [R41-sensors-logger] settings for pulse fish recordings
2025-09-11 [R4-sensors-logger] update for flona
2025-10-23 [R4-sensors-logger] increased version
2025-10-29 [loggerconf] updated device id retrieval
2025-10-29 [R4-sensors-logger] better test settings
2025-11-02 [loggerconf] export button
2025-11-07 updated to device metadata
2025-11-09 [SensorLogger] disable LEDs in low light
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2025-11-14 [loggerconf] delay between start recording und getting data
2025-11-16 fixed roles for ampl_info Menu
    [R4-logger.ino, R40-logger.ino, R40-recorder.ino]
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2025-11-16 [loggerconf] add LED blink test
2025-11-22 [DeviceID] moved from TeeRec
2025-11-22 [DeviceID] added DeviceID action
2025-11-22 [LoggerSettings] preparePaths() with and without DeviceID
2025-11-24 [LoggerSettings] possibility to make device id visible in admin mode only
2025-11-24 [loggerconf] switching mode sets focus to first parameter
2025-11-27 [loggerconf] fixed visibility of firmware button
2026-01-07 [Logger] fixed handling of random blinks
    [Logger.cpp, R4-logger.ino, R4-sensors-logger.ino]
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2026-03-24 [LoggerSettings] device id from device optional
2026-03-26 [R4-sensors-logger] power down PCMs before snooze
2026-04-02 [loggerconf] fixed y-axis scaling
2026-05-07 [loggerconf] cut plot data to same len
2026-06-01 [SetupPCM] improved setup message with ISC address and TDM data pin
2026-06-05 [R4-sensors-logger] added TDM data pin
2026-06-05 [R4-sensors-logger] fixed TDM bus
    [R4-sensors-logger.ino]
2026-06-12 [R5-logger] fixed 32 channel setup
    [R5-logger.ino, SetupTLV.cpp]
2026-06-12 [R5-logger] fixed sensors
2026-06-20 [R5.0] added battery voltage
2026-07-10 [R5.0] prepare for new boards
2026-08-07 [R5-logger] removed legacy PCB code
2026-08-07 [R5-logger] fixed initialization of tlv chips
    [R5-logger.ino]
2026-08-13 [SensorsLogger] check battery voltage in configure
2026-08-13 [R5-logger] added minimum battery voltage
2026-08-13 [SensorsLogger] no new files if battery voltage is too low
    [Logger.cpp, R5-logger.ino, SensorsLogger.cpp]
2026-08-14 [PowerSettings] settings for voltage thresholds
2026-08-14 [R5-logger] no more setClock() for I2C - the smalles supported value is 100kHz
2026-08-15 [I2CEEPROMStorage] support EEPROM via I2C bus
2026-08-15 [SetupTLV] prepare reversed channel mapping
    [SetupTLV.cpp]
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2026-08-16 [Electrodes] added electrode description
2026-08-16 [Electrodes] added location and added menu to all sketches
2026-08-16 [SetupTLV] optional reversal of input pin order
    [R5-logger.ino, SetupTLV.cpp]
2026-08-17 [R5-logger] adjusted start and stop voltages
2026-08-17 [CANLogger] improved timeout and error handling for detect and assign devices
    [CANFD.cpp, CANLogger.cpp]
2026-08-18 [CANFD] improved detect and assign devices
2026-08-19 [SetupTLV] roll channel order if four boards are used
2026-08-19 [SetupTLV] fixed channel ordering
    [SetupTLV.cpp]
2026-08-20 [SensorsLogger] shutdown_teensy() when battery is low
2026-08-21 [CANLogger] updated to three stage transmit protocol
2026-08-24 [CANLogger] insert device id into filename and sync in initialDelay()
2026-08-28 [SetupTLV] prepare highpass filter settings
2026-08-28 [SetupTLV] set highpass filter cutoff
2026-08-28 [I2CEEPROMStorage] fixed update()
2026-08-29 [utils] add copydata.py, a Python copy tool for larger card sets
    Streams each WAV off the card through wavpack, files it under
    site/grid, and sha256s it during the same read, so the drive carries a
    manifest of source hashes.
    That manifest is what the rest rests on: resume knows which files are
    actually complete, and the copy can be proven intact later without the
    cards still being present. By default 5% of each deployment is read
    back during the copy and the rest is provable on demand -- reading
    everything back inline roughly doubles a 4x500 GB run.
    Also copies the non-WAV sidecars the current firmware writes, checks
    free space before starting, skips the 0-byte file left when power is
    cut,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
2026-08-30 [CANLogger] put device id after "grid"
2026-08-30 [CANLogger] fixed power down message
    [CANLogger.cpp]
2026-08-30 [copydata.sh] wavpck is able to owverwrite interrupted files
2026-08-30 [copydata.sh] report files that were not copied
    wavpack's exit status is not checked. When it fails, the .wv is simply not
    there, the message scrolls past between the parallel jobs, and the script
    still prints 'finished copying in Ns!' and exits 0.
    This is not about the empty last file after a power loss. 'test -s' already
    handles that correctly and it stays silent, nothing changes there. It is
    about the cases where wavpack itself fails:
    destination full or not writable, a read error on a worn card, a wavpack
    that is not installed or not working.
    Tested. With a destination that could not be written, 3 of 5 files were
    missing and the script reported success. With a wavpack that fails o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
2026-08-30 [utils] add checkdata.sh, compares the cards against the archive
    After a copy run the archive holds no record of what should have been in it,
    so a complete archive and one with a hole in it look the same. This compares
    the two directly: for every non-empty .wav on a card it checks that the
    matching .wv is in the archive, same for the .csv and .yml. Empty files are
    skipped, so the last file after a power loss is not reported.
    Only file names are read, no audio. A full season by the numbers in
    copydata.sh (~87000 files) takes about 3.5 seconds. Silent and exit 0 when
    everything is there, so it can go at the end of a copy run.
    Works on archives made by either script.
2026-08-30 [copydata.py] drop the truncated-wav handling
    A logger that loses power leaves an empty file, not a half-written one, so
    the truncated-wav case this was built for does not occur. It carried a
    WavInfo field, a zstd fallback, a sampling rule, a manifest key and two
    summary sections, all for a state that never happens.
    The 0-byte case stays as it was: skipped by default, --keep-empty to copy
    them, reported in the summary.
2026-09-03 [R5] fixed blink timeout
    [Logger.cpp, R5-logger.ino]
2026-09-06 [R5-sensors] record sensors only from R5

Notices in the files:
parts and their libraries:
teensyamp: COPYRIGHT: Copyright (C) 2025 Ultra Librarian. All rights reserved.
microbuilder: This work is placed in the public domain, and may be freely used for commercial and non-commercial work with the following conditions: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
